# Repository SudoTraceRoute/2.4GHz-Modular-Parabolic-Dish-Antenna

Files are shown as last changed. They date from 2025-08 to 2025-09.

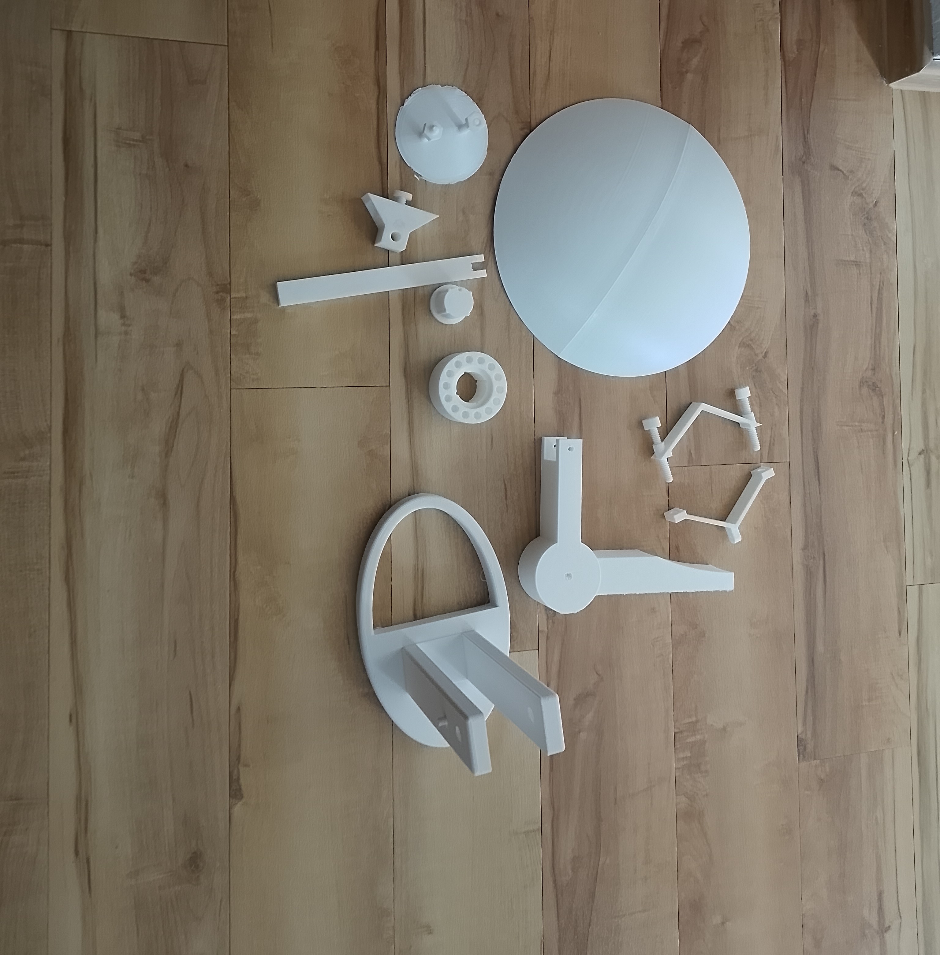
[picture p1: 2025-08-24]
Photos_of_antenna/IMG_20250716_165126 (1).jpg

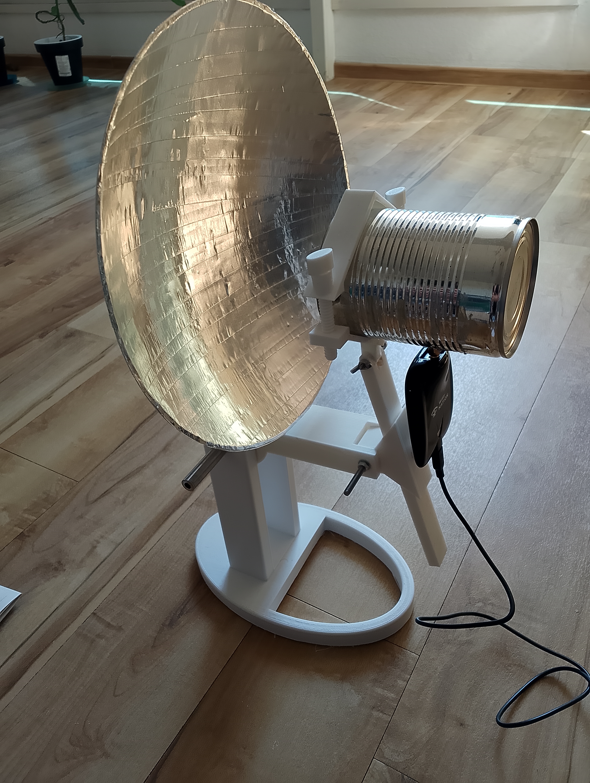
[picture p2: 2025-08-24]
Photos_of_antenna/IMG_20250824_151842.jpg

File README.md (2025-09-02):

# 2.4GHz-Modular-Parabolic-Dish-Antenna
3D-printed directional Wi-Fi antenna project with possibilities of various upgrades

This project showcases a **modular, 3D-printed parabolic dish antenna** optimized for 2.4GHz (Wi-Fi band) frequencies. Designed for experimentation and adaptability, it allows easy replacement of the dish, feed, and structural parts to support different frequencies and setups — including potential use cases in 5GHz or 5G ranges.

The antenna combines RF engineering principles with practical, low-cost materials and is intended for students, hobbyists, and network engineers interested in wireless signal enhancement.

-**ProjectGoal**

To create a functional, low-cost 2.4GHz directional antenna that is:
- **Modular** – parts can be swapped, resized, or upgraded
- **3D printable** – accessible and replicable with desktop 3D printers
- **Practical** – shows real signal gain in Wi-Fi environments

---

## 🛠️ Materials & Hardware

| Component | Details |
|---|---|
| **3D Printer** | Creality Ender 3 V3 SE |
| **Filament** | PLA |
| **Dish Diameter** | 30 cm |
| **Feed Element (Dipole)**| ~31.5 mm copper wire (~1 mm diameter) with heat-shrink insulation |
| **Can (Waveguide)** | Tin can (82 mm diameter, ~116 mm depth), RP-SMA male connector attached |
| **Feed Placement** | ~49 mm from can bottom (optimized for wave reflection and resonance) |
| **Reflective Surface** | Aluminum tape with electrically conductive adhesive |
| **Dish Shaft** | Stainless steel rod (recommended over PLA for strength) |
| **Tripod Mount** | 3D-printed nut adapter for phone/laser tripod compatibility |
| **Adjustable Tilt** | Wheel-based angle adjustment on the stand |

---

## ⚙️ Design Features

- **Modular construction**: All parts are designed for **easy assembly and replacement**:
  - Swap out dishes of different sizes by unscrewing the holder.
  - Replace or upgrade the feed can for higher frequencies (e.g., 5GHz).
  - Cantenna holder accepts different can diameters.
- **RF-Aware Feed Positioning**: Feed is carefully placed **~49 mm from the can bottom**, accounting for **reflected wave propagation**, not just 1/4 λ. This corrects a common mistake in similar builds.
- **Insulated Feed Element**: Copper feed is protected with heat-shrink tubing (<0.1 mm thick) to **prevent corrosion** while minimizing any capacitive interference.
- **Effective Reflector Surface**: Dish covered with **aluminum tape featuring conductive adhesive**, ensuring minimal signal loss across the parabolic surface.
- **Robust Stand Design**: Dish and shaft mount on a **metal support rod**, providing the strength to hold larger or heavier components.

---

## 📊 Performance Notes

- The feed is tuned **not by a simple 1/4 wavelength formula**, but based on real reflective path inside the can.
- The copper feed element is covered with **heat-shrink tubing** (less than 0.1mm thick) to prevent corrosion, without significantly impacting electrical properties.
- The dish surface is made conductive to **reduce energy loss** as signals reflect across it.

Preliminary signal strength tests show enhanced directional reception in the 2.4GHz Wi-Fi band, with measurable gain compared to typical router antennas. Results may vary depending on local interference and test environment.

---

## ✅ Skills Demonstrated

- RF theory: feed tuning, reflection, wavelength alignment
- Mechanical design: adjustable mounts, modular holders
- 3D modeling & printing: PLA, design for strength
- Signal performance testing (RSSI)
- Materials choice for conductivity and mechanical strength
- Documentation and open-source sharing

---

## 📝 License

This project is open source under the **MIT License** — feel free to modify, share, or build on it, with credit.

---

## 📬 Contact

Feel free to open an issue or fork the repo if you'd like to contribute or ask questions.

---

## PhotosOfAntenna

Complete antenna mounted on the tripod:
https://github.com/SudoTraceRoute/2.4GHz-Modular-Parabolic-Dish-Antenna/blob/main/Photos_of_antenna/IMG_20250824_152351%20(1).jpg

3D printed parts for the antenna:
https://github.com/SudoTraceRoute/2.4GHz-Modular-Parabolic-Dish-Antenna/blob/main/Photos_of_antenna/IMG_20250716_165126%20(1).jpg

---

## 🎯 Why I Built This

As a part of my hobby I'm building and testing real hardware to deepen my knowledge in RF behavior, Wi-Fi diagnostics, Linux tooling, and network infrastructure.  
I have interest in networking, programming and other fun stuff.

---

---

## ✅ Project Status: Complete

This hardware build is finished and has successfully demonstrated directional Wi-Fi reception improvements compared to standard omnidirectional antennas.

Further experimentation, signal testing, and network analysis will be explored in future, related projects using this antenna.

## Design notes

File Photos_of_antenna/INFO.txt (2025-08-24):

On this photos you can see the 3D parts that I have made, and also the photos of complete functional antenna. 
There is also a photo that shows some basic tools and materials that you will need to use in order to build it, 
because it's not a item that is ready to use right of the 3D printer.
There are some additional parts (not 3D printed, and not listed above), that you will need in order to complete this build.
It is necessary that you have some skills with tools, otherwise the injuries might follow.
If you dont know how to use drill to drill metal, or you dont know how to solder (needed to solder the antenna fed to the RP SMA connector, and RP SMA connector to the can), 
than this project is not for you. Please don't try to do it, because you will most likely get injured.  

IF YOU DECIDE TO BUILD THIS ANTENNA, PLEASE CONTACT ME FOR ANY QUESTIONS, I WOULD BE GLAD TO HELP.

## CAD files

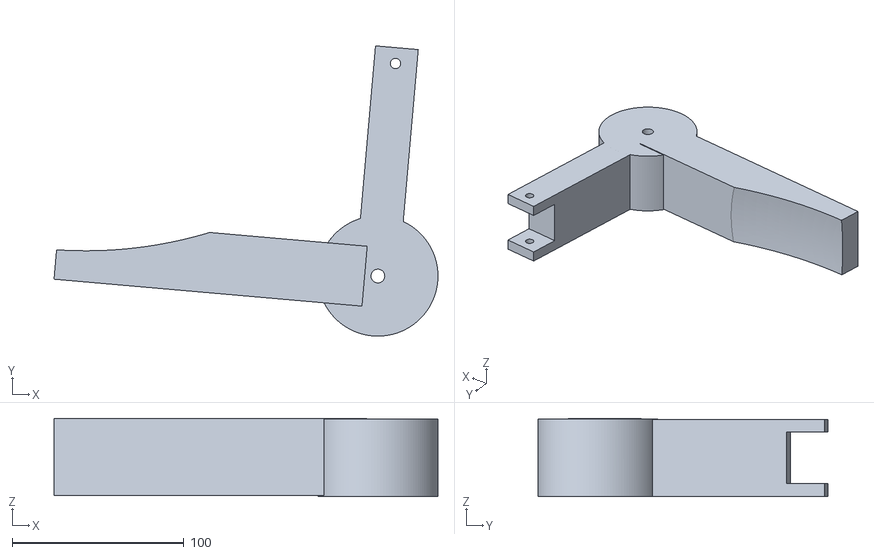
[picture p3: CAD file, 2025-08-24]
STL_files/Main_Holder.stl
223.6 x 169.0 x 45.5

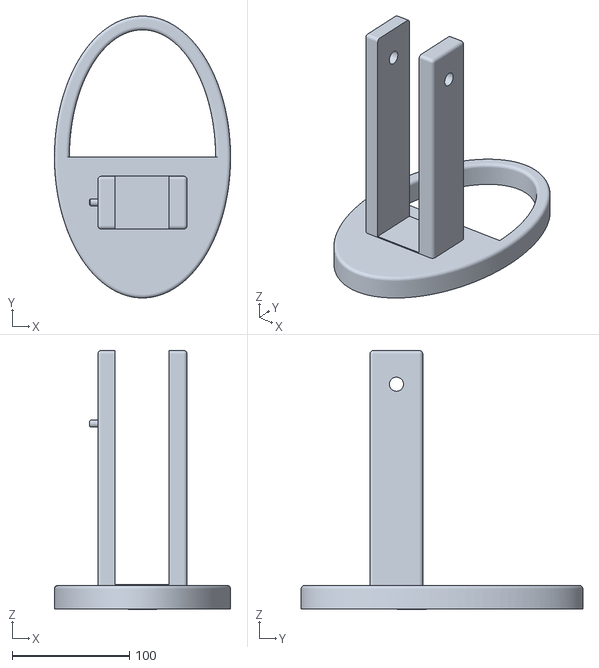
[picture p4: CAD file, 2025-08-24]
STL_files/Base_Holder.stl
150.0 x 240.0 x 220.5

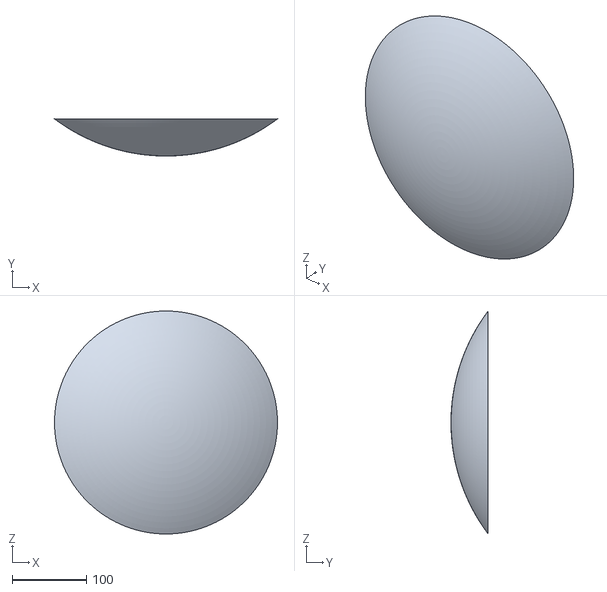
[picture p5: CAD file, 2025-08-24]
STL_files/Dish_30cm_diameter.stl
300.0 x 50.0 x 299.9

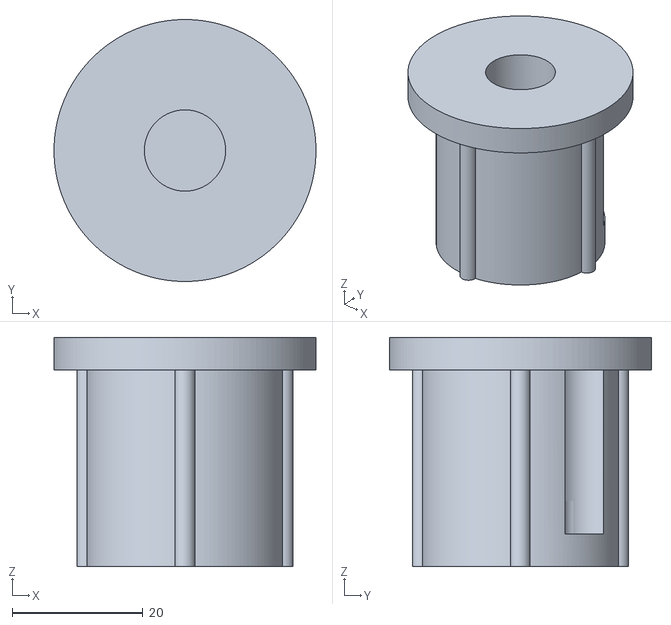
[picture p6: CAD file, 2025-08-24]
STL_files/Tilt_Adjusting_Wheel_2(inside).stl
40.0 x 40.0 x 35.0

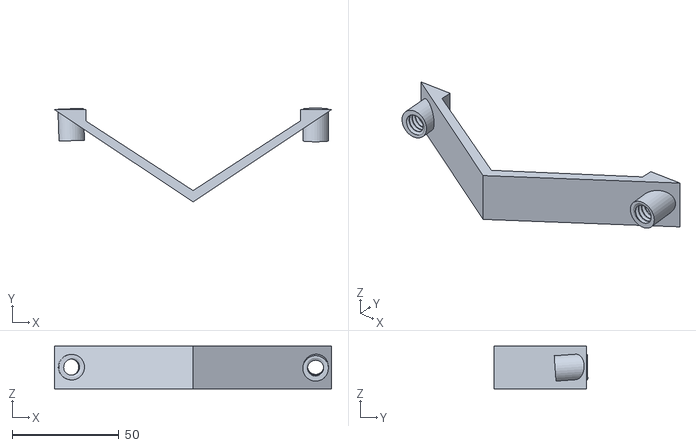
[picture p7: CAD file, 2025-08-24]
STL_files/Cantenna_Holder_Upper_part.stl
130.0 x 44.0 x 20.0

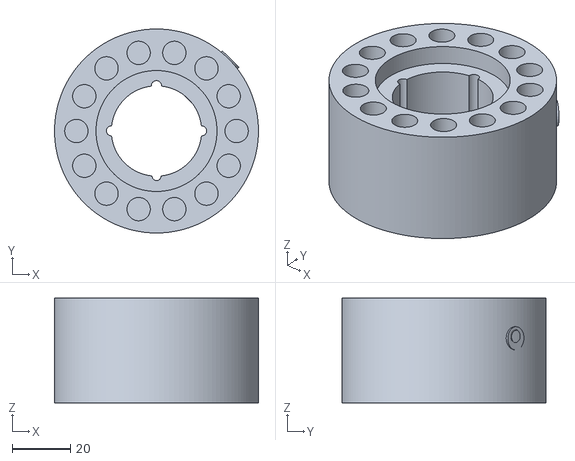
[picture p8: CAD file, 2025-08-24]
STL_files/Tilt_Adjusting_Wheel_1.stl
70.0 x 70.0 x 36.0

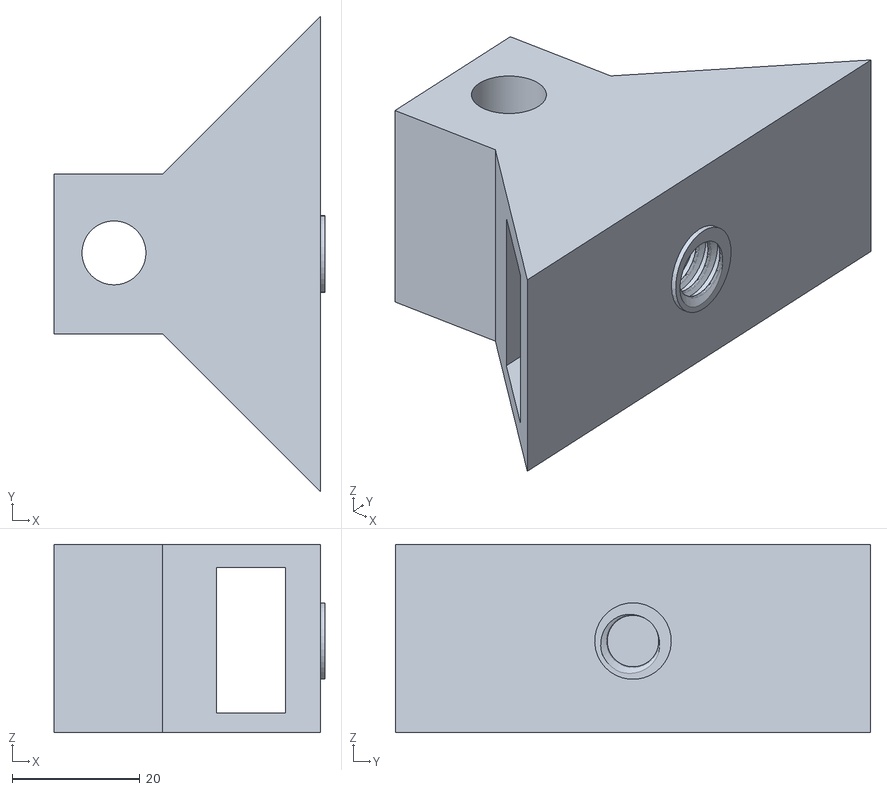
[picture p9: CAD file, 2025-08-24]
STL_files/Cantenna_Hight_Tilt_Adjuster.stl
42.5 x 74.5 x 29.5

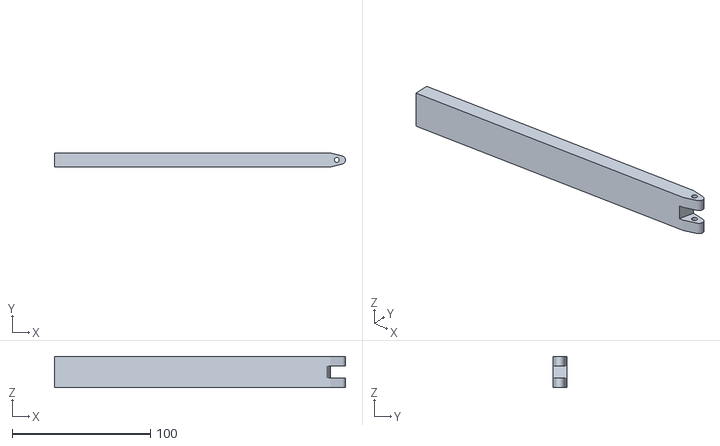
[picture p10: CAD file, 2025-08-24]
STL_files/Cantenna_Hight_Adjusting_Pole.stl
210.9 x 10.2 x 22.5

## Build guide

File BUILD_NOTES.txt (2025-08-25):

## ⚠️ Build Disclaimer

This is **not** a beginner project. The parts you see in this repository are **not ready-to-use straight from a 3D printer**.

To successfully build this antenna, you should already have experience with:

- **Drilling and cutting metal parts** (e.g., waveguide can, brackets)
- **Sanding and finishing 3D printed parts** to fit tolerances
- **Soldering** coaxial connectors (e.g., SMA/RP-SMA)
- **Basic electrical knowledge** (impedance, polarity, shielding)
- **Some understanding of Wi-Fi theory** (e.g., polarization, wavelength, antenna gain)

> If you're not already comfortable with these skills, I strongly recommend practicing them on simpler projects first.

### 🧱 What This Project Is:
- A hands-on experiment in building a high-gain directional Wi-Fi antenna
- A foundation for more advanced wireless/RF work
- A portfolio project showing practical IT/hardware skills

### ❌ What This Project Is Not:
- A plug-and-play antenna kit
- A no-tools-required project
- A suitable entry point for someone with no experience in electronics or RF hardware

---

## 🔧 Notes on Printed Parts

Even if you have a 3D printer:
- Some parts **will need to be drilled or widened** to fit actual hardware
- Alignments must be **measured and adjusted manually**
- Real-world tolerances vary between printers and materials

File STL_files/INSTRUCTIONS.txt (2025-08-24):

You will need some basic tools to adjust the 3d printed parts such as accu drill, drill bits, metal screws, cheap 2 component epoxy glue, 3d priting tools such as file, knifes etc)
The full list of the additional tools/materilas that I have used is comming soon.

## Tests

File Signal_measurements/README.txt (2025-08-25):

## 📊 Signal Testing & Comparison

Testing was conducted using:

- External USB Wi-Fi adapter with monitor mode (via `aircrack-ng`)
- `airodump-ng` for real-time signal strength (PWR)
- Controlled indoor setup with fixed placement
- ESSID "asdfgh"

| Antenna | Avg. PWR (dBm) | Notes |
|---|---|---|
| Omnidirectional | ~-33 dBm | Stable signal |
| 2.4GHz-Modular-Parabolic-Dish-Antenna | Peaks at **-26 dBm**, dips to -80 dBm | Strongest signal observed, but highly directional and sensitive to alignment |

### 🔍 Observations

- The custom antenna outperformed the omnidirectional one **in peak signal strength**.
- Oscillations in signal (from -26 to -80 dBm) were traced to:
  - **Environmental multipath reflections**
  - **Driver-level reporting variance** in `airodump-ng`
  - **High directionality**, making fine alignment crucial
- Polarization was correctly matched, and the feed was confirmed to be at the dish's focal point.

---

## 🧰 Tools Used

- `aircrack-ng` suite (`airodump-ng`, `airmon-ng`)
- `iwconfig` / `iw` for signal monitoring
- Linux (Debian-based distro)
- USB Wi-Fi adapter with monitor mode support

---

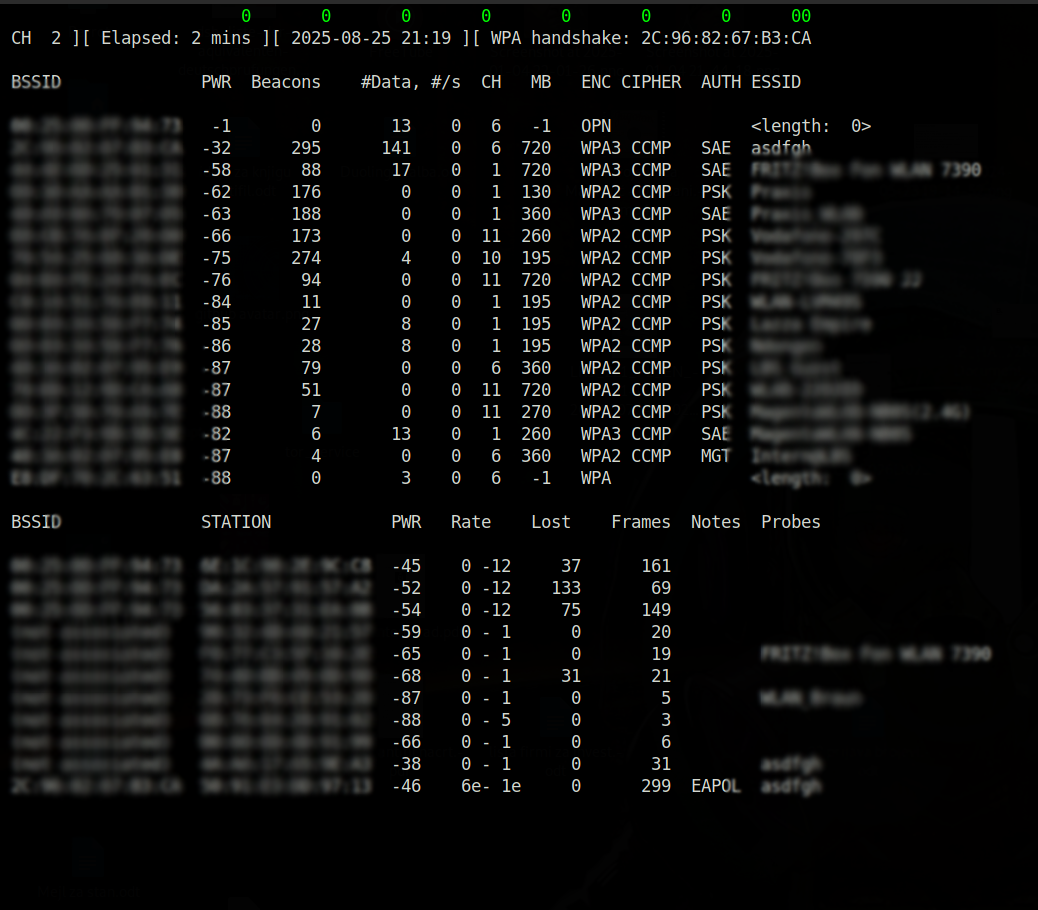
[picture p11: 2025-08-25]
Signal_measurements/Omnidirectional_default_external_antenna_.png

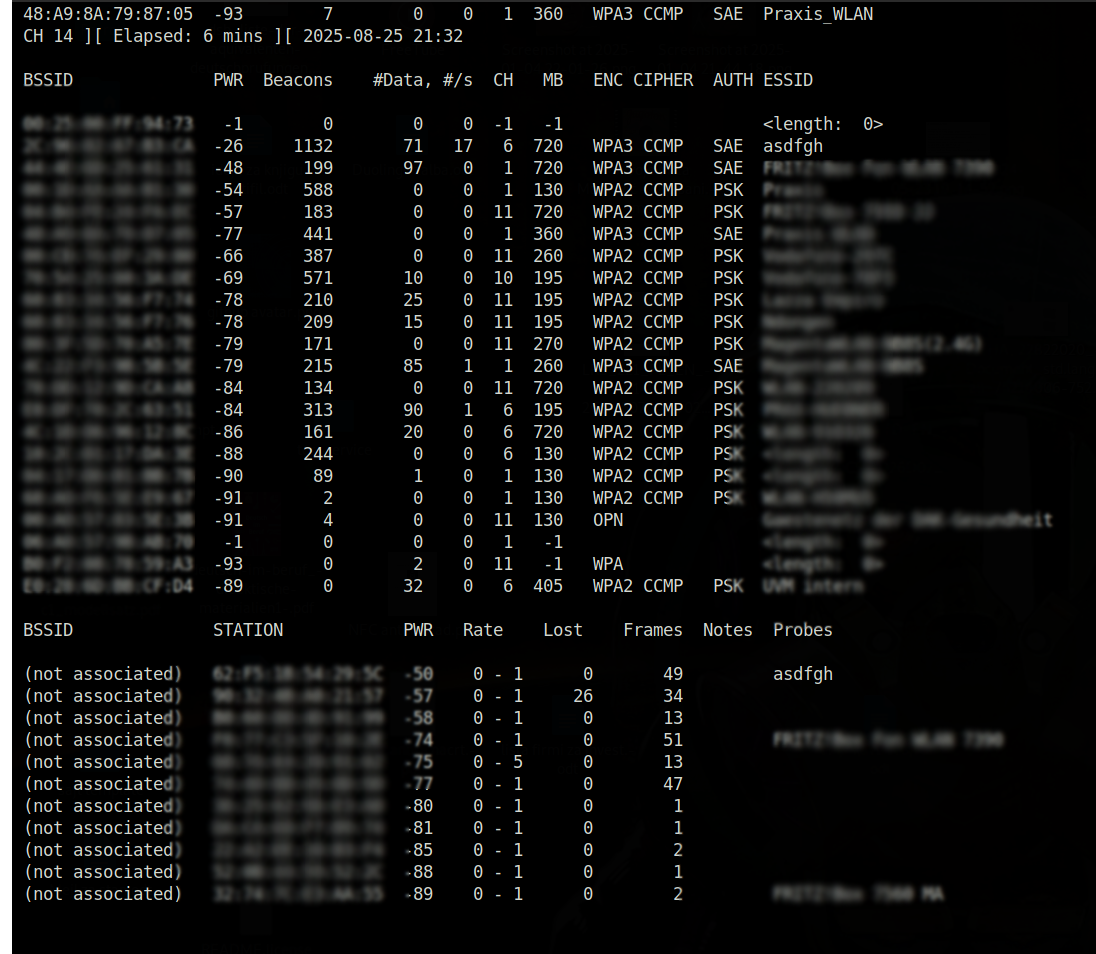
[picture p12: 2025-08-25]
Signal_measurements/Parabolic_dish_custom_antenna_directional.png
